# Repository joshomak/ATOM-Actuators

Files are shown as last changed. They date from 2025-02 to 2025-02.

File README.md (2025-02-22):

# ATOM-Actuators

This repository contains the source code, hardware files, and documentation for two quasi-direct-drive, closed-loop stepper motor actuators I designed and built as part of a robotic arm project during the 2024 winter break. From concept to completion, both actuators were designed, manufactured, and assembled in four days. Each actuator is 3D printed and features a unique gearbox design, an AS5600 magnetic encoder for precise position feedback, and is powered by a TMC2209 stepper motor driver controlled via an ESP32-S3 microcontroller.

This actuator is open source and free to use for any robotics projects. All the OnShape CAD files are contained [here](https://cad.onshape.com/documents/a7bd79262569e19a42552159/w/6b34bbca82999ac3877c186b/e/5aad9edadc693860d47861f7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).

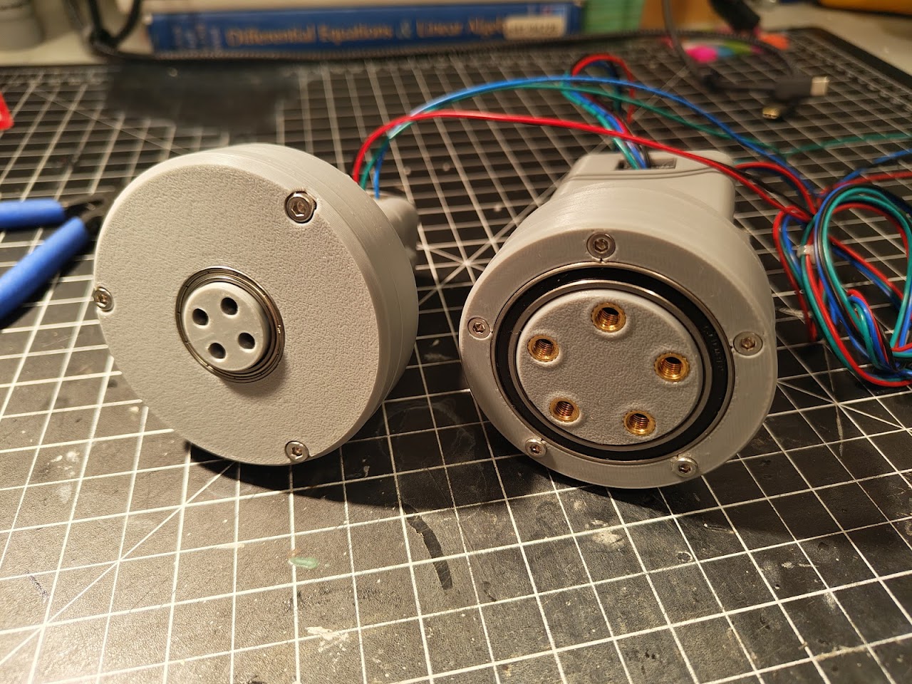
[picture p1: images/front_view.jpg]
Front View


## Hardware

### Actuator Specifications
| Feature | Actuator 1: Planetary NEMA 11 Gearbox | Actuator 2: Rolling Element Cycloidal NEMA17 Gearbox |
|---|---|---|
| **Motor** | NEMA 11 stepper motor | NEMA 17 stepper motor |
| **Gearbox** | Planetary gearbox | Rolling element cycloidal gearbox |
| **Reduction Ratio** | 4:1 | 9:1 |
| **Encoder** | AS5600 magnetic encoder | AS5600 magnetic encoder |
| **Driver** | TMC2209 stepper motor driver | TMC2209 stepper motor driver |
| **Microcontroller** | ESP32-S3 | ESP32-S3 |
| **Control Mode** | StealthChop | StealthChop |
| **Power Supply** | 12V-24V DC | 12V-24V DC |
| **3D Printed Material**  | PLA (intended: PCTG) | PLA (intended: PCTG) |

### Assembly Notes
- **Material**: While PLA was used for prototyping, PCTG is the intended filament for final parts due to its durability and heat resistance.
- **Printing**: The gearboxes were designed with the Bambu Lab A1 in mind, but any printer can be used. Ensure that parts with rotational symmetry or contact surfaces have **random seams** to evenly distribute wear.
- **Cooling**: The TMC2209 drivers can get very hot. Ensure sufficient cooling to avoid issues like melting breadboards.

## Firmware

The firmware for the actuators is written for the ESP32-S3 microcontroller and is located in the `/firmware` folder. A basic demo script, `Demo_Code.ino`, is included to get the actuators running. The script demonstrates:
- Controlling the TMC2209 stepper motor drivers via UART
- Reading position feedback from the AS5600 encoders
- Basic motor movement

### Key Features
- **Stepper Motor Control**: Utilizes the TMC2209's StealthChop mode for precise and quiet operation
- **Encoder Feedback**: Reads the AS5600 encoder data to monitor the shaft position
- **UART Communication**: Configures and controls the TMC2209 drivers via UART

### Dependencies
- **[TMC2209 Library](https://github.com/janelia-arduino/TMC2209)**: For interfacing with the TMC2209 stepper driver
- **[AS5600 Library](https://github.com/RobTillaart/AS5600)**: For reading encoder data
- **ESP32 Arduino Core**: For ESP32-S3-specific functions and UART communication

### Notes
- Velocity control and feedforward feedback control were not implemented due to time limitations.
- Gearbox efficiency measurements were not performed.

## Bill of Materials (BOM)

The BOM for each actuator is included in the `/hardware` folder. Each BOM is accompanied by a **BOM balloon callout drawing** to assist with assembly. The BOM includes all components required for each actuator, such as motors, encoders, fasteners, and bearings.

## Electrical Schematics

The electrical schematics for the actuators are provided in the `/electrical` folder. The schematic is designed in KiCad and includes the connections between the ESP32-S3, AS5600 encoder, TMC2209 driver, and stepper motor.

### Schematic Overview
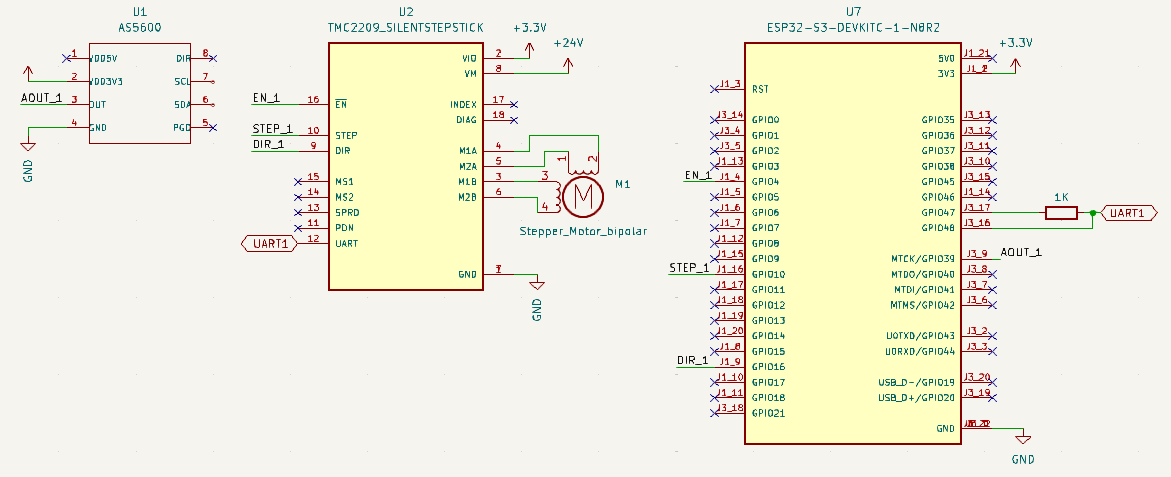
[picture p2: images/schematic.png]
Schematic


### AS5600 Encoder Pinout
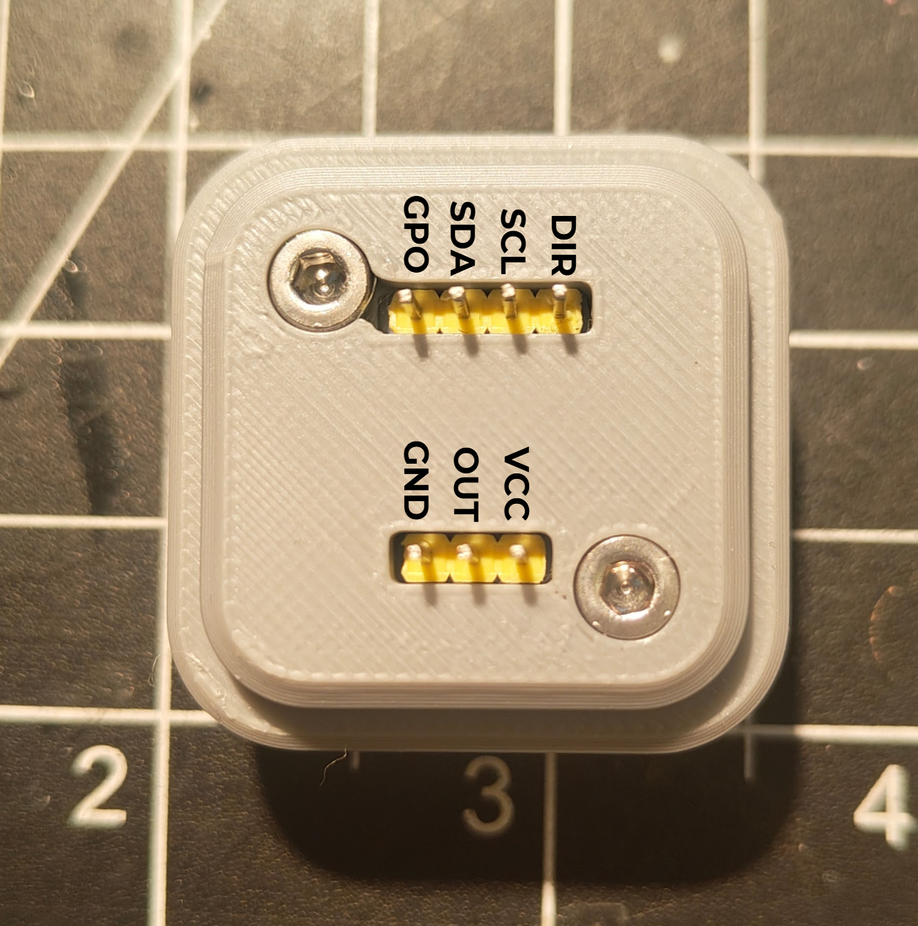
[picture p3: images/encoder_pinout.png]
Encoder Pinout


## Assembly Instructions

### 3D Models
- The STEP files for each actuator and their individual components are included in the `/hardware` folder. These files can be used for reference or modification in CAD software.

### Assembly Guide
1. Refer to the **BOM balloon callout drawing** in the `/hardware` folder for part identification and placement.
2. Use the STEP files to visualize the assembly process.
3. Follow the electrical schematics to connect the ESP32-S3, TMC2209, AS5600, and stepper motor.
4. Secure all components using the appropriate fasteners and ensure proper alignment of the gearbox and encoder.

## License

This project is licensed under the **MIT License**. This permissive license allows for reuse, modification, and distribution, provided the original license terms are included. For more details, see the [LICENSE](LICENSE) file.

## Notes
- Ensure proper heat dissipation for the TMC2209 drivers, especially at higher currents.
- Calibrate the AS5600 encoder to ensure accurate position feedback.
- Test the actuators at low speeds initially to avoid mechanical failures.

For questions or issues, please open an issue in this repository or contact the maintainer.

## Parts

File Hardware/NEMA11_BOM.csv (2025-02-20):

Item | Name | Quantity | Part number
1 | Top_Ring_Gear | 1
2 | Top_Planet_Carrier | 1
3 | Sun_Gear | 1
4 | Square thin nut grade B M3x0.5 | 1
5 | Sensor Magnet | 1
6 | Planet_Gear | 1
7 | Planet_Gear | 1
8 | Planet_Gear | 1
9 | Plain washer small grade A M5 | 6
10 | Parallel Pin 5 x 10 | 3
11 | M3 Heat Set Insert | 13
12 | Hex socket head cap screw M3x0.50 x 6 | 2
13 | Hex socket head cap screw M3x0.50 x 45 x 18 | 3
14 | Hex socket head cap screw M3x0.50 x 20 | 3
15 | Hex socket head cap screw M3x0.50 x 10 | 3
16 | Hex nut grade A & B M3x0.5 | 2
17 | Cup point hex socket set screw M3x0.5 x 4 | 1
18 | Bottom_Ring_Gear | 1
19 | Bottom_Planet_Carrier | 1
20 | Ball Bearing 2RS 4x10x5mm | 3 | MR105-2RS-INOX-ZEN
21 | AS5600 Sensor | 1
22 | Actuator_Housing_Shroud | 1
23 | Actuator_Housing_Sensor_Mount | 1
24 | Actuator_Housing_Sensor_Cap | 1
25 | 6704ZZ | 2
26 | 11HS20-0674S Stepper Motor | 1

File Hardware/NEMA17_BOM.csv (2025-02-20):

Item | Name | Quantity | Part number
1 | Wave Generator | 1
2 | Square thin nut grade B M3x0.5 | 1
3 | Separator (Output Shaft) | 1
4 | Sensor Magnet | 1
5 | Nylon Spacers 3.2mm ID 7mm OD 5mm H | 9
6 | M5 Heat Set Insert | 5
7 | M3 Heat Set Insert | 8
8 | Hex socket head cap screw M3x0.50 x 6 | 2
9 | Hex socket head cap screw M3x0.50 x 45 x 18 | 3
10 | Hex socket head cap screw M3x0.50 x 22 x 18 | 5
11 | Hex nut grade A & B M3x0.5 | 2
12 | Gearbox Lid | 1
13 | Gearbox Base | 1
14 | Eccentric Cam (Input shaft) | 1
15 | Cup point hex socket set screw M3x0.5 x 6 | 1
16 | Body (Inner Cycloid Ring Gear) | 1
17 | AS5600 Sensor | 1
18 | Actuator_Housing_Shroud | 1
19 | Actuator_Housing_Sensor_Mount | 1
20 | Actuator_Housing_Sensor_Cap | 1
21 | 6808-2RS Bearing | 1
22 | 6704ZZ Bearing | 1
23 | 17HS19-2004S1 Stepper Motor | 1

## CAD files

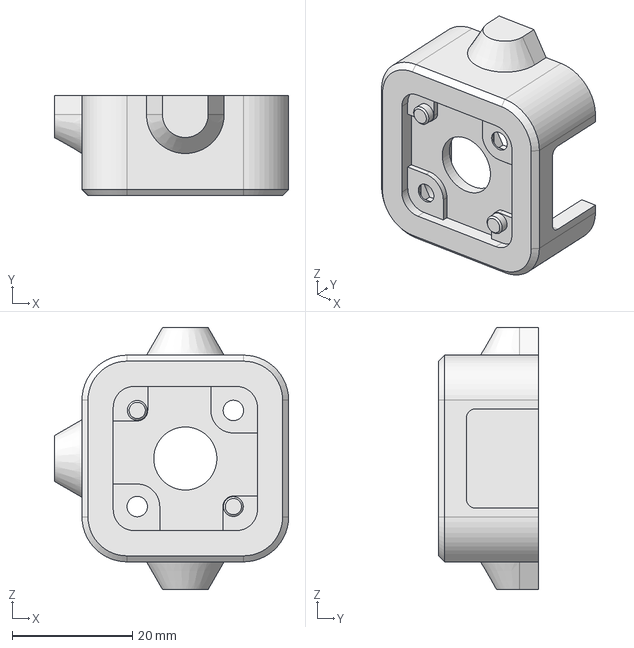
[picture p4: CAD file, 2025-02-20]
Hardware/(Individual Component Files) NEMA 11 - Planetary/STEP Files/Actuator Housing (NEMA11) - Actuator_Housing_Sensor_Mount.step
39.0 x 16.7 x 43.6 mm

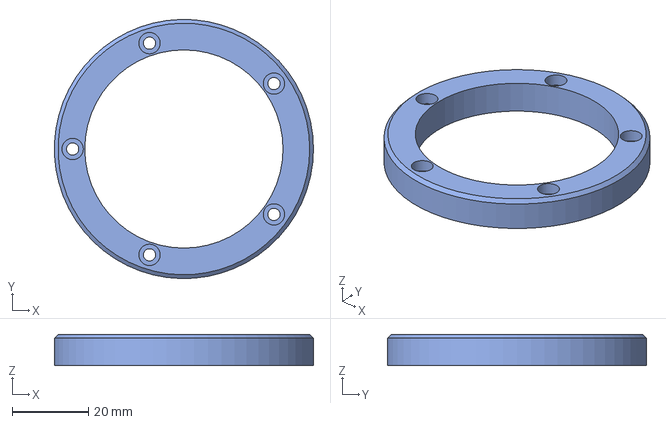
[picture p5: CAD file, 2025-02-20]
Hardware/(Individual Component Files) NEMA 17 - Cycloidal/STEP Files/Rolling Element Cycloid Components - Gearbox Lid.step
68.0 x 68.0 x 8.20 mm

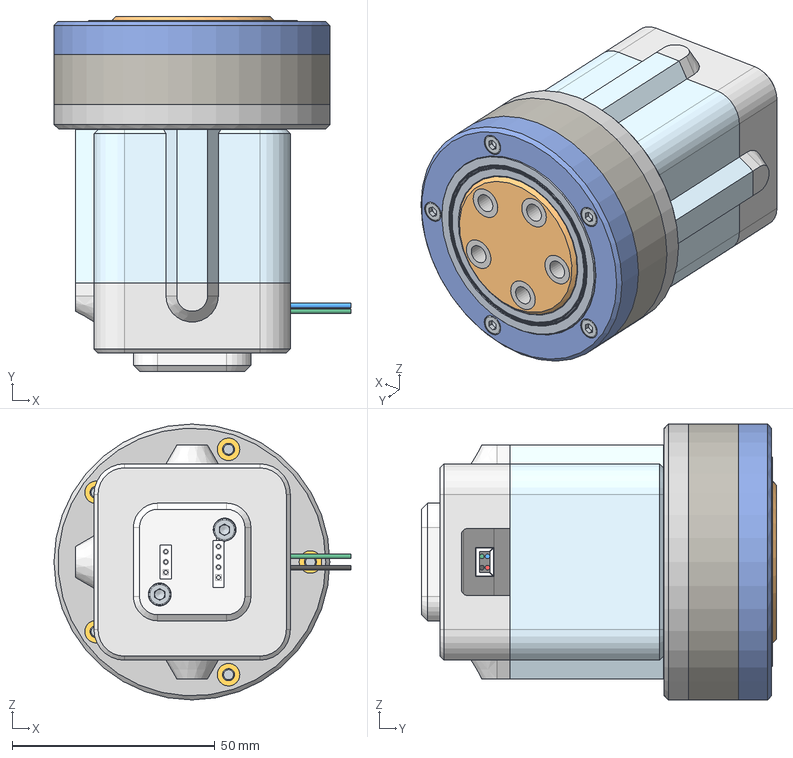
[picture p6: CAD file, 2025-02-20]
Hardware/NEMA17 Actuator.step
73.2 x 87.5 x 68.0 mm
Actuator_Housing_Shroud
AS5600
Sensor Magnet
17HS19-2004S1
Actuator_Housing_Sensor_Cap
Hex socket head cap screw M3x0.50 x 6 x 2
Hex socket head cap screw M3x0.50 x 45 x 18 x 3
Actuator_Housing_Sensor_Mount
M3 Heat Set Insert x 8
Hex nut grade A & B M3x0.5 x 2
Rolling Element x 9
Wave Generator
Gearbox Lid
Separator (Output Shaft)
M5 Heat Set Insert x 5
Gearbox Base
Eccentric Cam (Input shaft)
Hex socket head cap screw M3x0.50 x 22 x 18 x 5
Cup point hex socket set screw M3x0.5 x 6
Body (Inner Cycloid Ring Gear)
4668K271_Permanently Lubricated Stainless Steel Ball Bearing x 25
6704ZZ
Square thin nut grade B M3x0.5

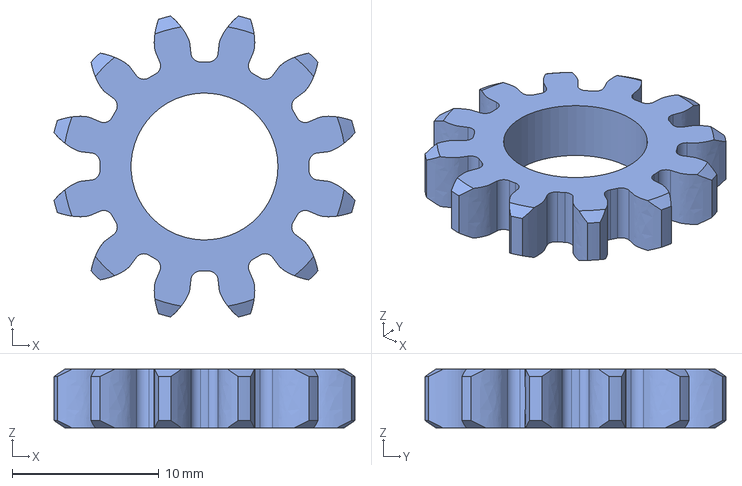
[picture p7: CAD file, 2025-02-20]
Hardware/(Individual Component Files) NEMA 11 - Planetary/STEP Files/Planetary Gearbox Components - Planet_Gear.step
20.5 x 20.5 x 4.00 mm

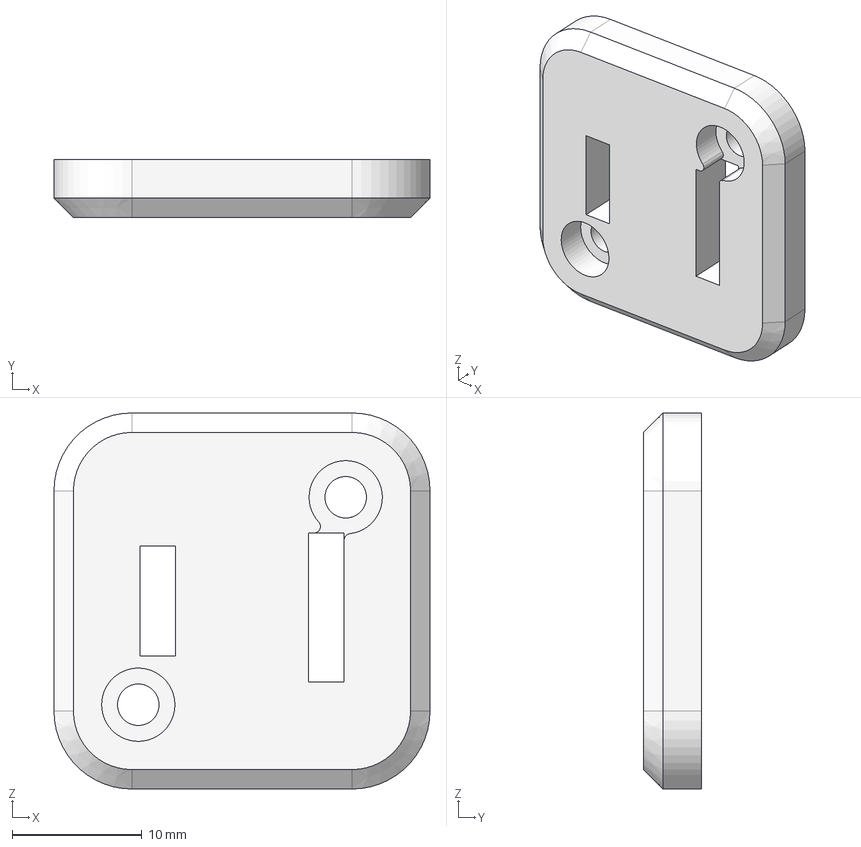
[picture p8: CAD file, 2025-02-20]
Hardware/(Individual Component Files) NEMA 17 - Cycloidal/STEP Files/Actuator Housing (NEMA17) - Actuator_Housing_Sensor_Cap.step
29.0 x 4.50 x 29.0 mm

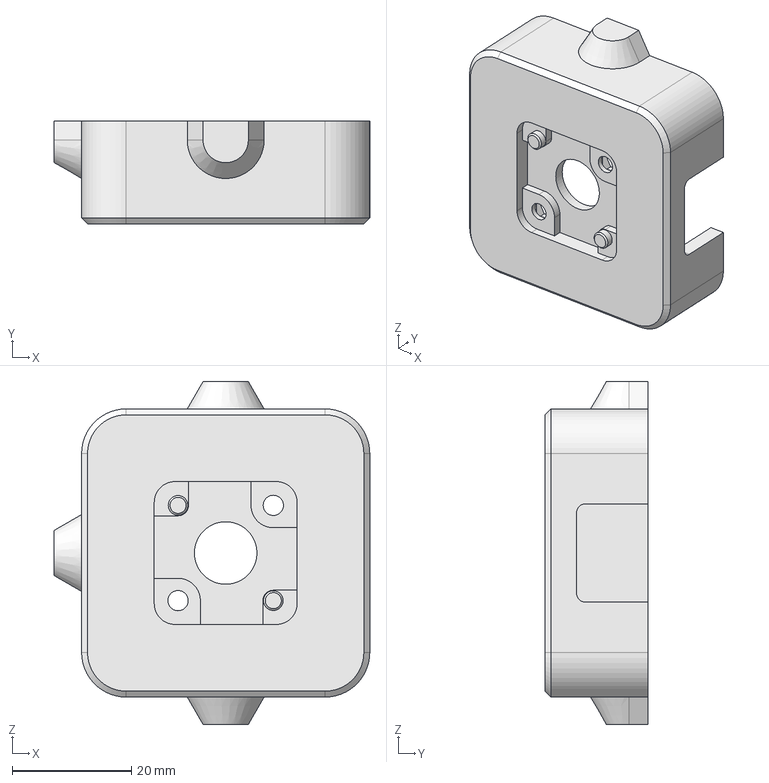
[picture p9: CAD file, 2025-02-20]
Hardware/(Individual Component Files) NEMA 17 - Cycloidal/STEP Files/Actuator Housing (NEMA17) - Actuator_Housing_Sensor_Mount.step
53.0 x 17.3 x 57.6 mm

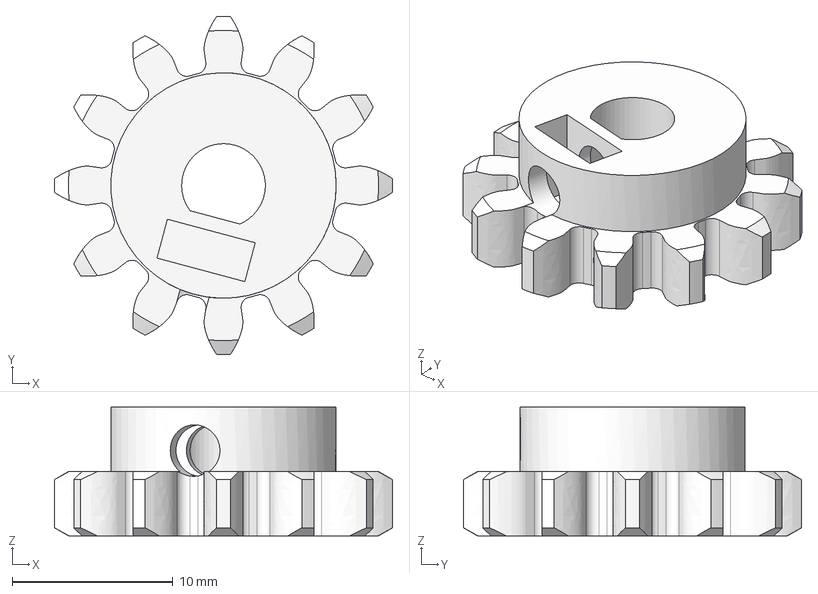
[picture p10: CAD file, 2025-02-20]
Hardware/(Individual Component Files) NEMA 11 - Planetary/STEP Files/Planetary Gearbox Components - Sun_Gear.step
21.0 x 21.0 x 8.00 mm

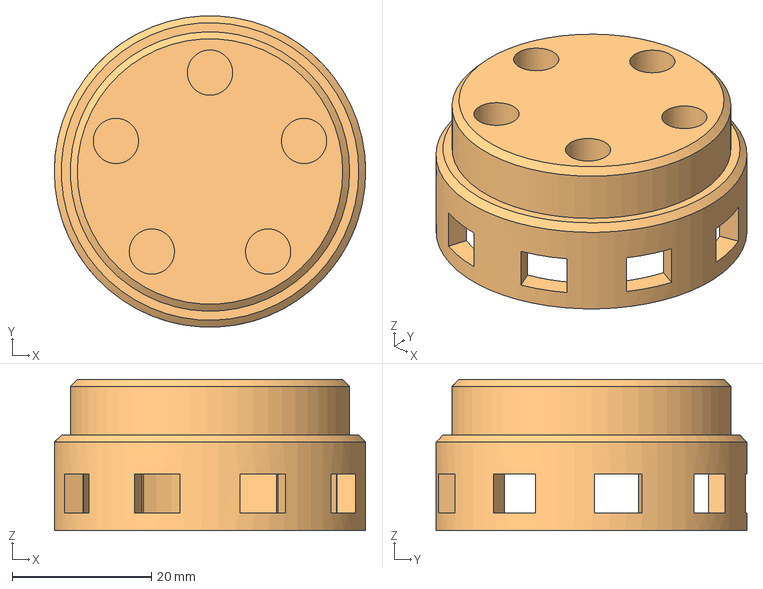
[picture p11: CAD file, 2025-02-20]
Hardware/(Individual Component Files) NEMA 17 - Cycloidal/STEP Files/Rolling Element Cycloid Components - Separator (Output Shaft).step
44.7 x 44.6 x 21.7 mm

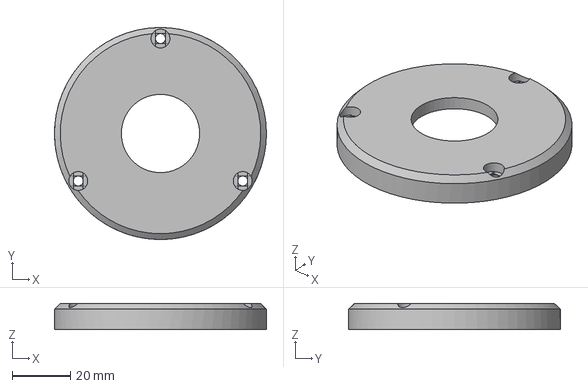
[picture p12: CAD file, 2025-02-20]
Hardware/(Individual Component Files) NEMA 11 - Planetary/STEP Files/Planetary Gearbox Components - Top_Ring_Gear.step
73.0 x 73.0 x 9.00 mm

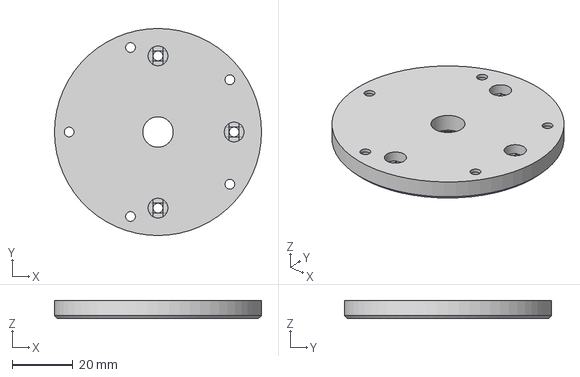
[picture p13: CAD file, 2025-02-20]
Hardware/(Individual Component Files) NEMA 17 - Cycloidal/STEP Files/Rolling Element Cycloid Components - Gearbox Base.step
68.0 x 68.0 x 6.00 mm

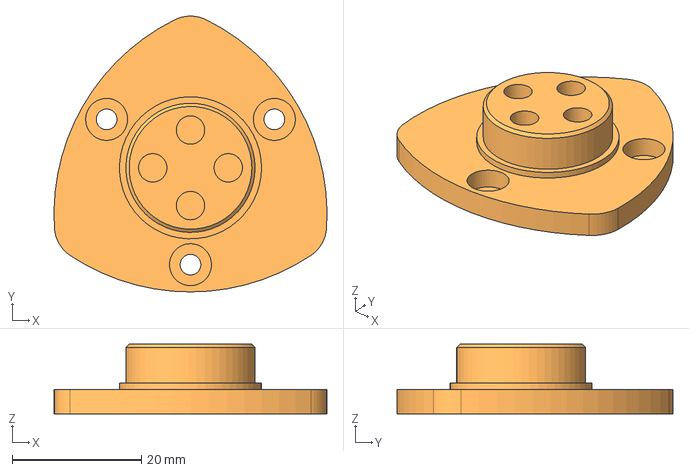
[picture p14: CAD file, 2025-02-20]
Hardware/(Individual Component Files) NEMA 11 - Planetary/STEP Files/Planetary Gearbox Components - Top_Planet_Carrier.step
42.3 x 42.7 x 10.8 mm

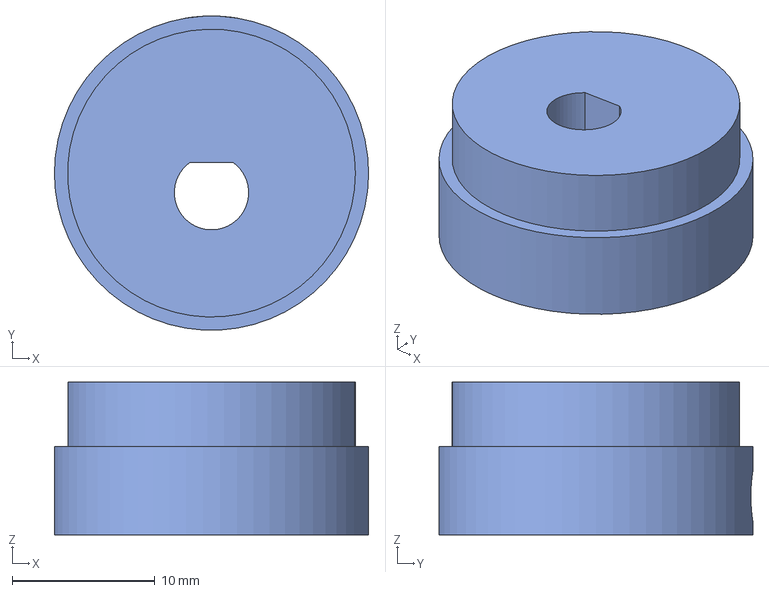
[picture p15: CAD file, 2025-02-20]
Hardware/(Individual Component Files) NEMA 17 - Cycloidal/STEP Files/Rolling Element Cycloid Components - Eccentric Cam (Input shaft).step
22.0 x 22.0 x 10.7 mm

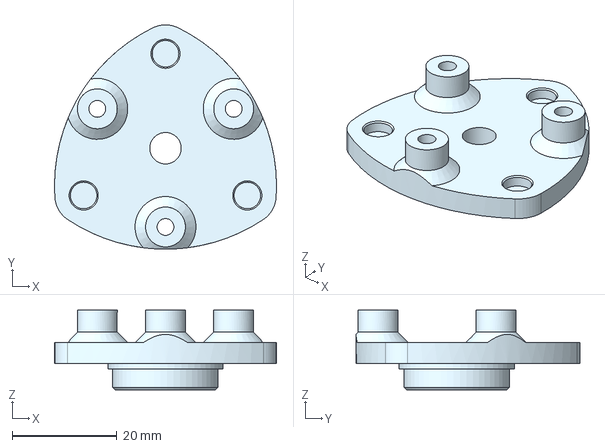
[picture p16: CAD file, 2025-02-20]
Hardware/(Individual Component Files) NEMA 11 - Planetary/STEP Files/Planetary Gearbox Components - Bottom_Planet_Carrier.step
42.3 x 42.7 x 15.2 mm

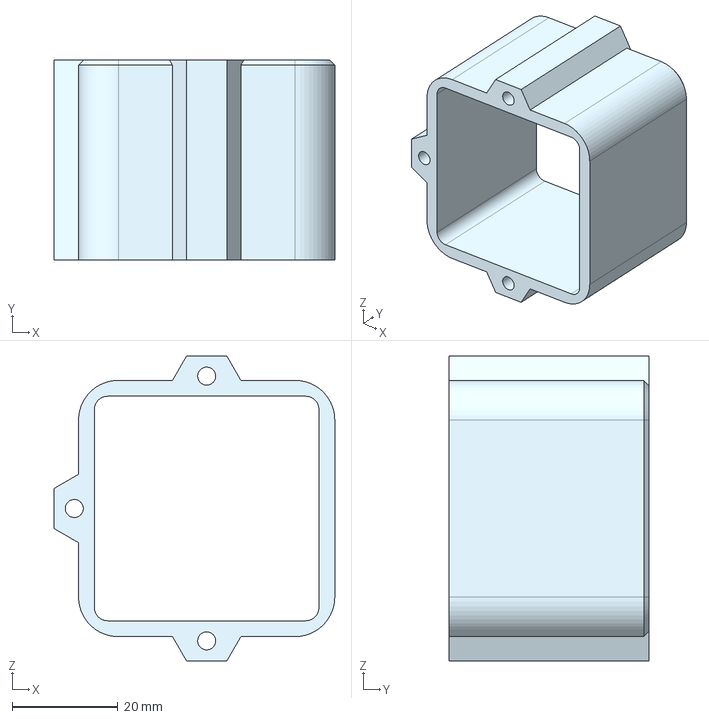
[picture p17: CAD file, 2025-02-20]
Hardware/(Individual Component Files) NEMA 17 - Cycloidal/STEP Files/Actuator Housing (NEMA17) - Actuator_Housing_Shroud.step
53.0 x 37.8 x 57.6 mm

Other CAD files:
Hardware/(Individual Component Files) NEMA 11 - Planetary/STEP Files/Actuator Housing (NEMA11) - Actuator_Housing_Sensor_Cap.step
Hardware/(Individual Component Files) NEMA 11 - Planetary/STEP Files/Planetary Gearbox Components - Bottom_Ring_Gear.step
Hardware/(Individual Component Files) NEMA 17 - Cycloidal/STEP Files/Rolling Element Cycloid Components - Wave Generator.step
Hardware/(Individual Component Files) NEMA 11 - Planetary/STEP Files/Actuator Housing (NEMA11) - Actuator_Housing_Shroud.step
Hardware/(Individual Component Files) NEMA 17 - Cycloidal/STEP Files/Rolling Element Cycloid Components - Body (Inner Cycloid Ring Gear).step

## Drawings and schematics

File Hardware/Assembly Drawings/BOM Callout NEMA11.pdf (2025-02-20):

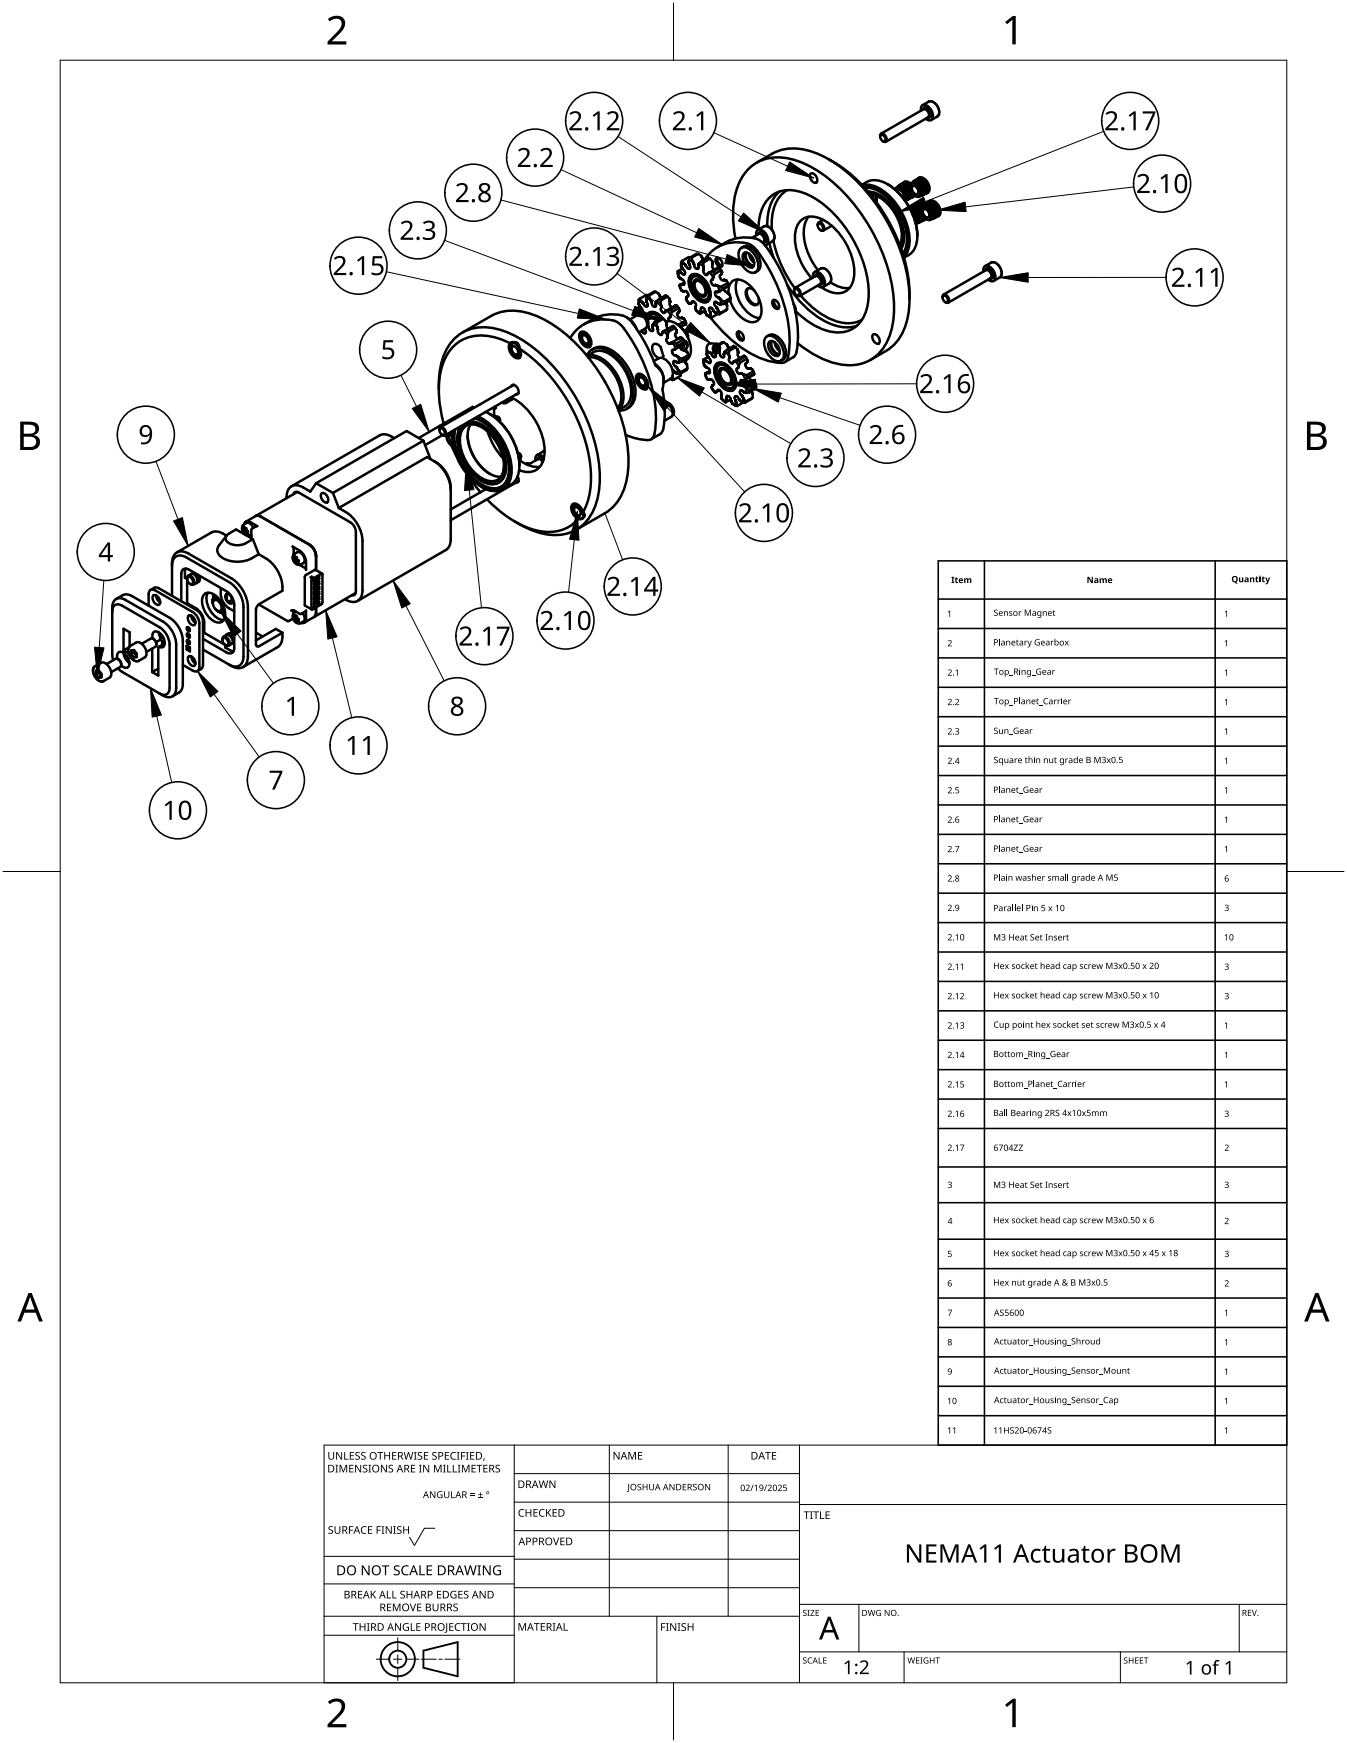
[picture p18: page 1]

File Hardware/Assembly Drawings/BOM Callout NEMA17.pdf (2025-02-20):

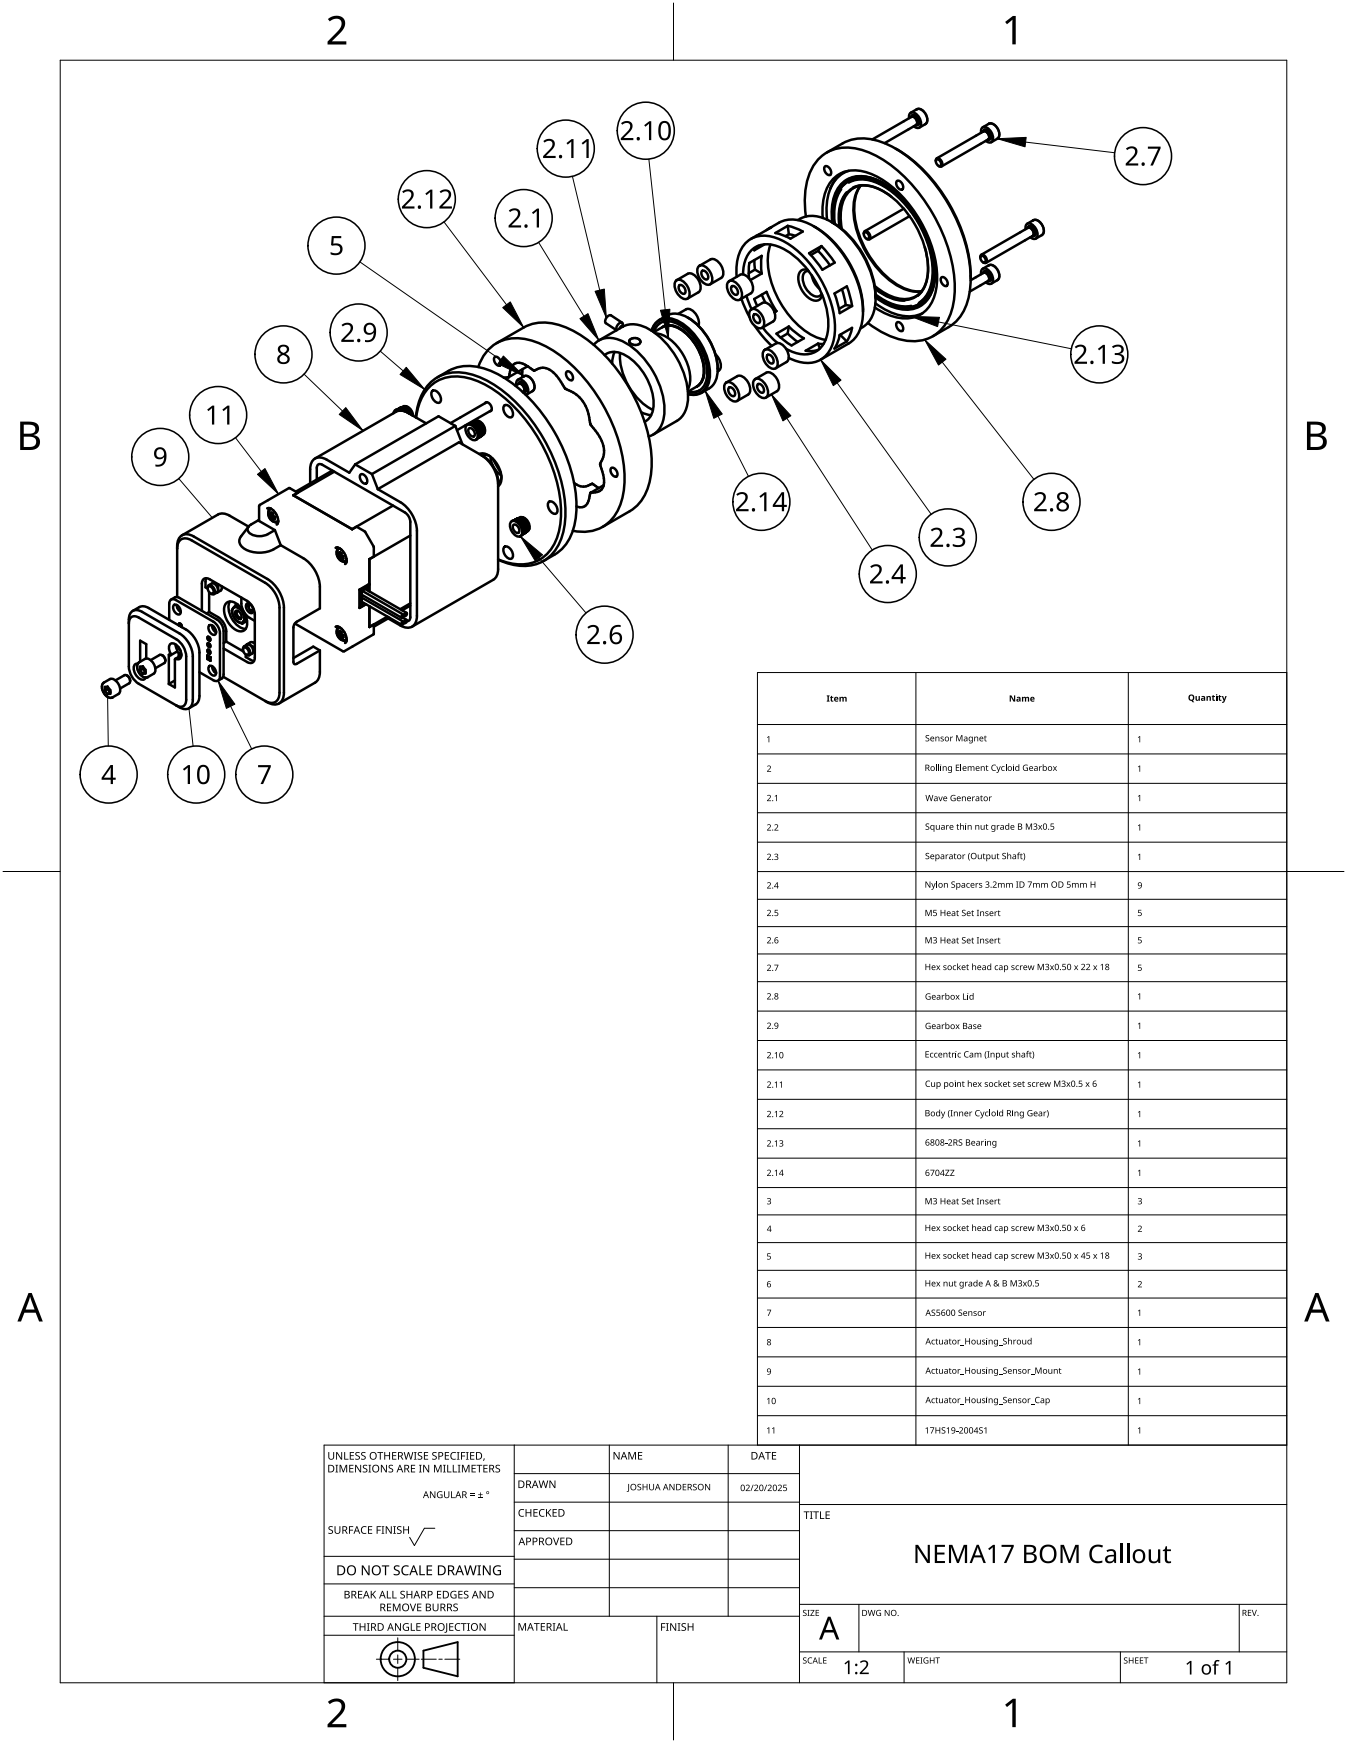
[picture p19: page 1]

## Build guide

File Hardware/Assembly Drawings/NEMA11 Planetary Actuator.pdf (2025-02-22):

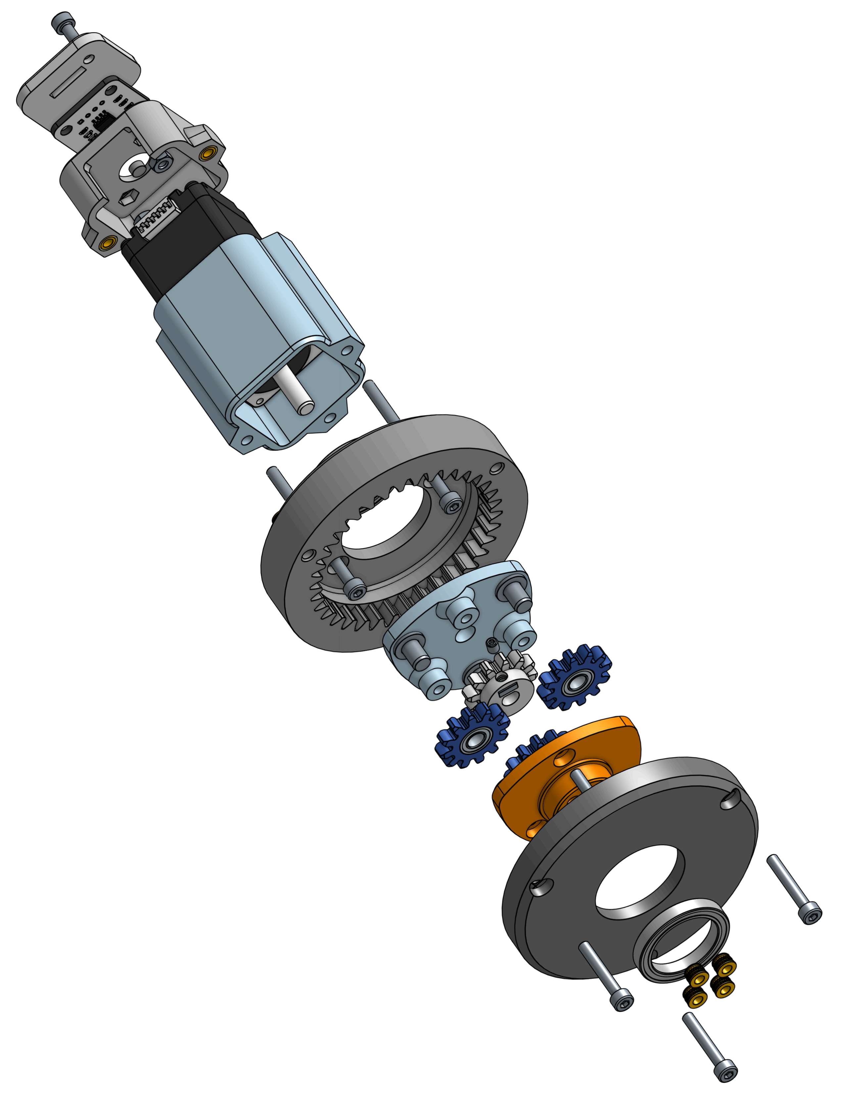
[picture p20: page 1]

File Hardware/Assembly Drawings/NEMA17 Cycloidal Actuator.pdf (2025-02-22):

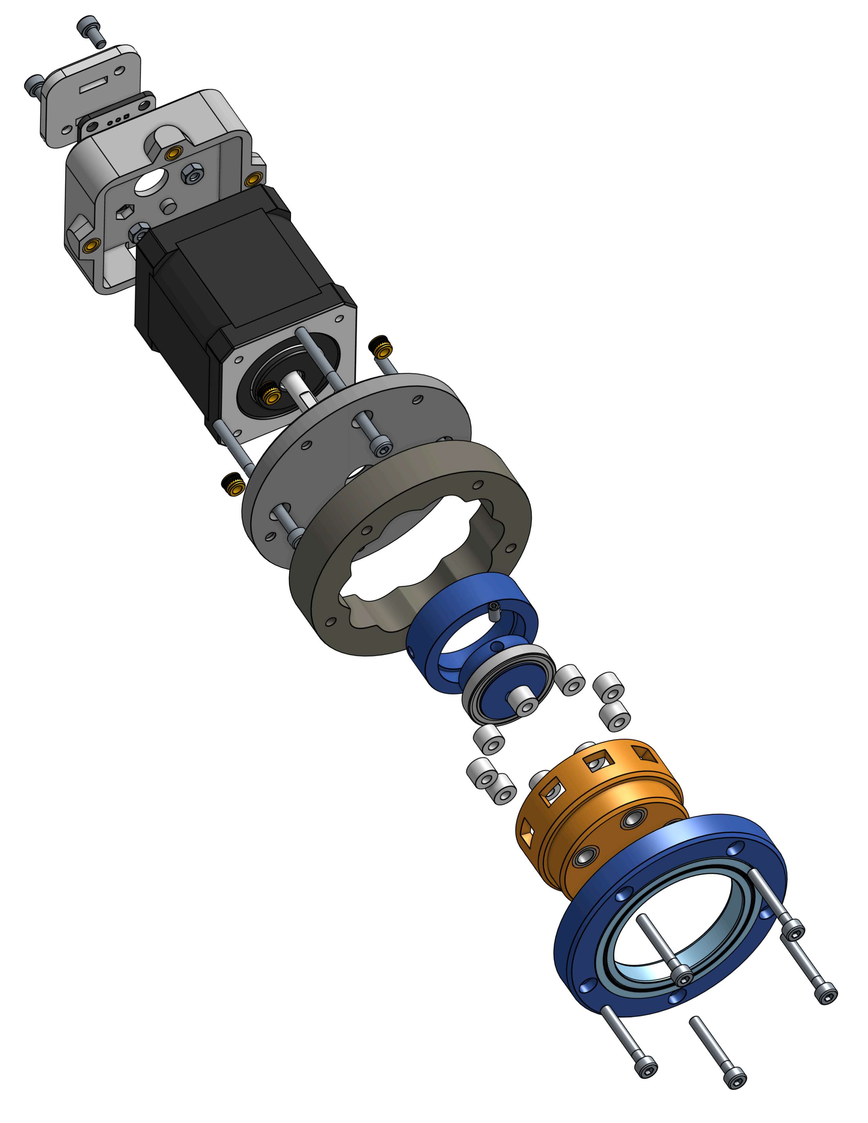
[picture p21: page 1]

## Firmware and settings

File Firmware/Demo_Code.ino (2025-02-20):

#include <TMC2209.h>
#include "AS5600.h"

// This example will not work on Arduino boards without HardwareSerial ports,
// such as the Uno, Nano, and Mini.
//
// See this reference for more details:
// https://www.arduino.cc/reference/en/language/functions/communication/serial/

HardwareSerial & serial_stream = Serial2;

const int RX_PIN = 10;
const int TX_PIN = 14;
const int AS5600_ADC_PIN = 3;

const long SERIAL_BAUD_RATE = 115200;
const int DELAY = 1000;
const int32_t VELOCITY = 40000;

// current values may need to be reduced to prevent overheating depending on
// specific motor and power supply voltage
const uint8_t RUN_CURRENT_PERCENT = 100;
const float MOTOR_STEP_ANGLE = 1.8;
const uint16_t MICROSTEPS = 16;


// Instantiate TMC2209

TMC2209 stepper_driver;
//AS5600 as5600;   // Use default Wire


void setup()
{
  // Init Serial
  Serial.begin(SERIAL_BAUD_RATE);
  stepper_driver.setup(serial_stream, SERIAL_BAUD_RATE, TMC2209::SERIAL_ADDRESS_0, RX_PIN, TX_PIN);
  //delay(DELAY);

  // Init I2C interface
  //Wire.begin(16, 17);

  // AS5600 Setup
  // as5600.begin(4);  // Set direction pin
  // as5600.setDirection(AS5600_CLOCK_WISE);  // Default, just be explicit
  // int b = as5600.isConnected();
  // Serial.print("Connect: ");
  // Serial.println(b);
  // Serial.println(as5600.getAddress());
  // pinMode(AS5600_ADC_PIN, INPUT);


  // Driver Initial Setup
  stepper_driver.setRunCurrent(RUN_CURRENT_PERCENT);
  stepper_driver.enableAutomaticCurrentScaling();
  stepper_driver.enableAutomaticGradientAdaptation();
  stepper_driver.enableCoolStep();
  stepper_driver.setHardwareEnablePin(15);
  stepper_driver.setMicrostepsPerStep(MICROSTEPS);
  stepper_driver.enable();
  Serial.println("Stepper Configuration Complete!");

  delay(2000);


  // StealthChop Automatic Tuning
  int step_per_rotation = 360 / MOTOR_STEP_ANGLE;
  int32_t microsteps_per_period = (6 * MICROSTEPS * step_per_rotation) / 0.715;
  delay(200); //AT#1
  stepper_driver.moveAtVelocity(microsteps_per_period); //AT#2



  //stepper_driver.moveAtVelocity(VELOCITY);

}

void loop()
{
  if (not stepper_driver.isSetupAndCommunicating())
  {
    Serial.println("Stepper driver not setup and communicating!");
    return;
  }

  bool hardware_disabled = stepper_driver.hardwareDisabled();
  TMC2209::Settings settings = stepper_driver.getSettings();
  TMC2209::Status status = stepper_driver.getStatus();

  if (hardware_disabled)
  {
    Serial.println("Stepper driver is hardware disabled!");
  }
  else if (not settings.software_enabled)
  {
    Serial.println("Stepper driver is software disabled!");
  }
  else if ((not status.standstill))
  {
    Serial.print("Shaft_Velocity: ");
    Serial.print(VELOCITY);
    
    //Serial.print("\tAngle_Read: ");
    //Serial.print(as5600.readAngle()); //for I2C interface

    int rawADC = analogRead(AS5600_ADC_PIN); // Raw ADC reading
    float voltage = (rawADC * 3.3) / 4095.0; // Convert to voltage (3.3V reference, 12-bit ADC)
  
    Serial.print("\tV_out: ");
    Serial.print(voltage, 3);

    //uint32_t interstep_duration = stepper_driver.getInterstepDuration();
    //Serial.print("which is equal to an interstep_duration of ");
    //Serial.println(interstep_duration);
  }
  else
  {
    Serial.println("Not moving, something is wrong!");
  }

  Serial.println();
  delay(2000);
}
